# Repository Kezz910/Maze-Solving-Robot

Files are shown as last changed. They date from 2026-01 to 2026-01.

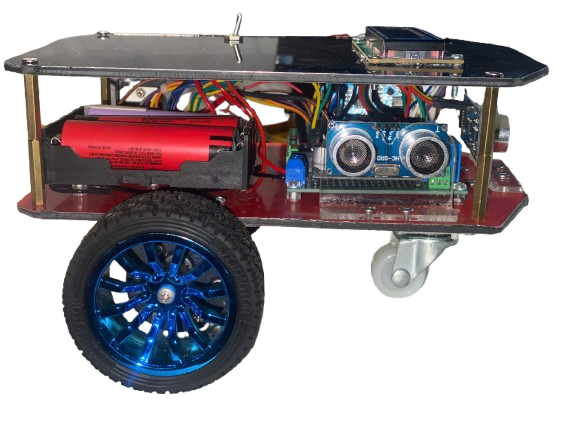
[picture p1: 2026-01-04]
hardware/ben_phai_robot.png

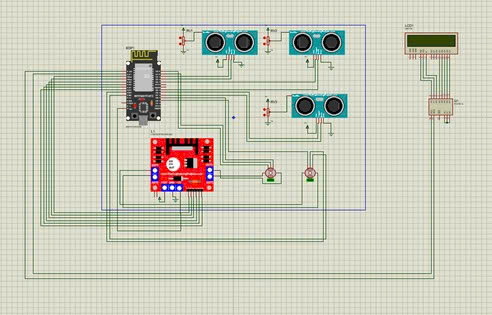
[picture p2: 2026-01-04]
hardware/sơ_đồ_nguyên_lý.jpg

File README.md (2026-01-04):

## Maze-Solving Robot (ESP32)

### 1. Tổng quan
Dự án xây dựng một robot tự hành có khả năng **tự di chuyển trong mê cung theo dạng lưới**, sử dụng cảm biến để nhận biết tường/vật cản và thuật toán để quyết định hướng đi.  
Hệ thống được thiết kế theo hướng **vừa vận hành thực tế vừa có khả năng giám sát dữ liệu**, nhằm phục vụ kiểm thử thuật toán và đánh giá chất lượng điều khiển trong môi trường mê cung.

Mục tiêu của đề tài là:
- Robot có thể **tự khám phá mê cung** và xử lý được các tình huống như ngã rẽ, vòng lặp, ngõ cụt.
- **Ghi nhận dữ liệu** (khoảng cách cảm biến, trạng thái di chuyển) để quan sát và phân tích trên dashboard.
- Ổn định chuyển động nhờ phản hồi encoder, giảm sai lệch do cơ khí và tải.

### 2. Kiến trúc hệ thống
Hệ thống gồm 3 lớp chính:

#### (1) Lớp cảm biến – nhận biết môi trường
Robot sử dụng **03 cảm biến siêu âm HC-SR04** bố trí theo 3 hướng **trước / trái / phải** để đo khoảng cách đến tường.  
Tại mỗi “bước” trong mê cung, robot cập nhật khoảng cách và phân loại đường đi: có thể đi thẳng, có thể rẽ, hoặc bị chặn.

#### (2) Lớp điều khiển chuyển động – chấp hành
Robot dùng **02 động cơ DC có encoder** điều khiển qua **L298N**. Encoder được dùng để:
- cân bằng tốc độ hai bánh khi đi thẳng,
- hỗ trợ điều khiển rẽ/quay ổn định hơn,
- hạn chế sai số tích lũy do lệch cơ khí.

Robot có LCD 16x2 (I2C) hiển thị thông tin cơ bản trong quá trình chạy.

#### (3) Lớp truyền thông – giám sát
Robot kết nối Wi-Fi và **truyền dữ liệu qua MQTT** (publish/subscribe). Dữ liệu được hiển thị bằng **Node-RED dashboard** để theo dõi realtime và hỗ trợ đánh giá quá trình chạy.

Nguồn cấp dùng pin 18650 cho phần công suất; khối điều khiển dùng hạ áp **LM2596** để ổn định cho ESP32 và ngoại vi.

### 3. Nguyên lý hoạt động (luồng thực thi)
Luồng chạy được tổ chức theo vòng lặp:
1. **Khởi tạo** ESP32, thiết lập GPIO/Timer, khởi tạo LCD và (tuỳ chọn) kết nối Wi-Fi + MQTT.
2. **Đọc cảm biến** (trước/trái/phải) để xác định các hướng có thể đi.
3. **Ra quyết định hướng đi** dựa trên luật ưu tiên và trạng thái đường đã đi (mục 4).
4. **Điều khiển động cơ**: phát PWM qua L298N; dùng encoder để cân bằng hai bánh và giảm lệch hướng.
5. **Cập nhật trạng thái**: lưu dấu đường đã đi trong ma trận biểu diễn mê cung, đồng thời gửi dữ liệu lên MQTT/Node-RED.
6. Lặp lại cho đến khi **tới đích** hoặc người dùng dừng.

Điểm quan trọng: robot di chuyển theo từng “ô” trong lưới mê cung; mỗi lần hoàn thành 1 ô thì mới cập nhật cảm biến và quyết định bước tiếp theo.

### 4. Thuật toán tìm đường và chiến lược tránh lặp
Robot áp dụng **thuật toán Trémaux** để xử lý mê cung có vòng lặp/ngõ cụt.  
Ý tưởng chính là **đánh dấu số lần đi qua mỗi ô/nhánh** (ví dụ: 0 – chưa đi, 1 – đã đi, 2 – hạn chế đi lại), từ đó:
- ưu tiên các hướng chưa đi qua,
- nếu gặp ngõ cụt thì quay lui,
- giảm khả năng chạy vòng lặp vô hạn.

Thuật toán được lưu bằng mảng/ma trận 2D đại diện lưới mê cung để robot có thể “nhớ” trạng thái đường đi.

### 5. Mô hình mê cung & thử nghiệm
Mê cung được thiết kế theo dạng lưới ô vuông để robot dễ quy ước di chuyển.  
Trong thử nghiệm:
- cảm biến siêu âm đáp ứng ổn định ở khoảng cách làm việc,
- động cơ hoạt động tốt với nguồn thực tế (có dòng khởi động lớn hơn dòng ổn định),
- việc dùng encoder giúp robot cân bằng tốt hơn, hạn chế lệch khi đi thẳng,
- Node-RED dashboard hiển thị dữ liệu theo thời gian thực, thuận tiện quan sát quá trình robot ra quyết định.

### 6. Cấu trúc thư mục repo
- `firmware/` : chương trình ESP32 (đọc cảm biến, điều khiển động cơ, encoder, MQTT)
- `hardware/` : sơ đồ đấu nối, mạch nguồn/driver, hình ảnh phần cứng
- `docs/` : mô tả hệ thống, lưu đồ, hình minh họa
- `results/` : hình ảnh, log, video minh họa kết quả chạy
- `algorithm` : Chi tiết thuật toán hoạt động thực tế

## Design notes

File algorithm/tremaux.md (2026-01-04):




# Mô tả chi tiết giải thuật lập trình (Maze Solving Robot)

## 1) Ý tưởng chung
Robot di chuyển theo các **cảm biến hợp lệ**:
- `cb0`: Thẳng
- `cb1`: Trái
- `cb2`: Phải

Quy tắc ưu tiên cơ bản: **Thẳng → Trái → Phải**, nhưng có xét thêm điều kiện **ô đã đi qua** (đánh dấu 0/1/2) để ưu tiên đi vào ô chưa đi lần nào.

Quy ước đánh dấu ô:
- `0`: chưa đi qua
- `1`: đã đi qua 1 lần
- `2`: đường cụt / đã quay đầu / đi lại

---

## 2) Bảng mô tả từng bước theo tọa độ

| Tọa độ | Hướng robot hiện tại | Cảm biến hợp lệ | Thực thi lệnh |
|---|---|---|---|
| (5,2) | BẮC | Trái (cb1) | Gọi hàm xoay trái 90° và đi thẳng. Đánh dấu ô (5,2) từ 0 → 1. |
| (5,1) | TÂY | Phải (cb2) | Xoay phải 90° và đi thẳng 1 ô. Đánh dấu ô = 1. |
| (4,1) | BẮC | Phải (cb2) | Xoay phải 90° và đi thẳng. Đánh dấu ô = 1. |
| (4,2) | ĐÔNG | Trái (cb1) | Xoay trái 90° và đi thẳng. Đánh dấu ô = 1. |
| (3,2) | BẮC | Trái (cb1) | Xoay trái 90° và đi thẳng. Đánh dấu ô = 1. |
| (3,1) | TÂY | Thẳng (cb0), Phải (cb2) | Ưu tiên **thẳng–trái–phải**. Thẳng→(3,0), phải→(2,1). Cả hai ô đều 0 nên ưu tiên **đi thẳng**. |
| (3,0) | TÂY | Trái (cb1) | Xoay trái 90° và đi thẳng. Đánh dấu ô = 1. |
| (5,0) | NAM | ĐƯỜNG CỤT | Xoay 180° và đi thẳng (quay đầu). Đánh dấu ô = 2. |
| (4,0) | BẮC | Thẳng (cb0) | Đi thẳng. Đánh dấu ô = 2. |
| (3,0) | BẮC | Phải (cb2) | Xoay phải và đi thẳng. Đánh dấu ô = 2. |
| (3,1) | ĐÔNG | Thẳng (cb0), Trái (cb1) | Thẳng và trái đều trống, nhưng thẳng→(3,2) đã = 1, còn trái→(2,1) chưa đi. ⇒ Xoay trái và đi thẳng. Đánh dấu (3,1) = 2. |
| (2,1) | BẮC | Phải (cb2) | Xoay phải và đi thẳng. Đánh dấu ô = 1. |
| (2,2) | ĐÔNG | Thẳng (cb0), Trái (cb1) | Ưu tiên đi thẳng vì 2 ô đều chưa đi qua lần nào. |
| (2,3) | ĐÔNG | Phải (cb2) | Xoay phải và đi thẳng. Đánh dấu ô = 1. |
| (3,3) | NAM | Thẳng (cb0), Trái (cb1) | Ưu tiên đi thẳng. Đánh dấu ô = 1. |
| (4,3) | NAM | Thẳng (cb0) | Chạy thẳng. Đánh dấu ô = 1. |
| (5,3) | NAM | ĐƯỜNG CỤT | Xoay 180° và đi thẳng. Đánh dấu ô = 2. |
| (4,3) | BẮC | Thẳng (cb0) | Đi thẳng. Đánh dấu ô = 2. |
| (3,3) | BẮC | Thẳng (cb0), Phải (cb2) | Thẳng không ưu tiên vì đã đi 1 lần, còn phải chưa đi ⇒ rẽ phải đi hướng mới. |
| (3,4) | ĐÔNG | Trái (cb1), Phải (cb2) | Hai ô đều 0 ⇒ ưu tiên rẽ trái. |
| (2,4) | BẮC | Thẳng (cb0) | Đi thẳng. Đánh dấu ô = 1. |
| (1,4) | BẮC | Thẳng (cb0), Trái (cb1) | Ưu tiên đi thẳng. Đánh dấu ô = 1. |
| (0,4) | BẮC | ĐƯỜNG CỤT | Xoay 180° và đánh dấu ô = 2. |
| (1,4) | NAM | Thẳng (cb0), Phải (cb2) | Thẳng→(2,4) đã đi 1 lần ⇒ loại. Xoay phải 90° và đi thẳng. Đánh dấu ô = 1. |
| (1,3) | TÂY | Thẳng (cb0) | Chạy thẳng. Đánh dấu ô = 1. |
| (1,2) | TÂY | Thẳng (cb0), Trái (cb1) | Thẳng→(1,1) chưa đi ⇒ chạy thẳng. |
| (1,1) | TÂY | Thẳng (cb0), Phải (cb2) | Ưu tiên chạy thẳng. Đánh dấu ô = 1. |
| (1,0) | TÂY | Trái (cb1) | Xoay trái 90° và đi thẳng. Đánh dấu ô = 1. |
| (2,0) | NAM | ĐƯỜNG CỤT | Xoay 180° và chạy thẳng. Đánh dấu ô = 2. |
| (1,0) | BẮC | Phải (cb2) | Xoay phải 90° và chạy thẳng. Đánh dấu ô = 2. |
| (1,1) | ĐÔNG | Thẳng (cb0), Trái (cb1) | Thẳng là ô đã đi 1 lần ⇒ ưu tiên rẽ trái và đi thẳng. |
| (0,1) | BẮC | (Đến đích) | Xét điều kiện đã đến đích ⇒ xe dừng chạy. |

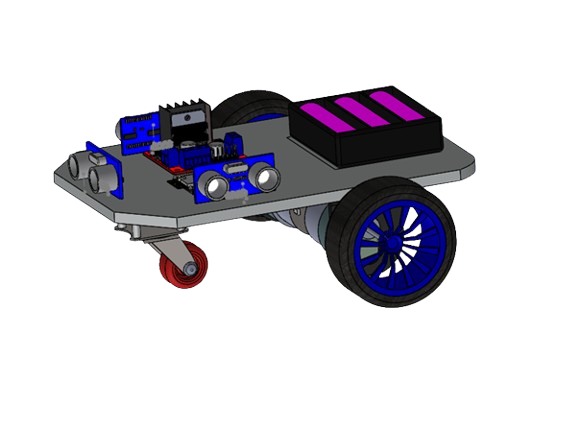
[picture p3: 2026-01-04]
hardware/SolidWorks/robot_3d.png

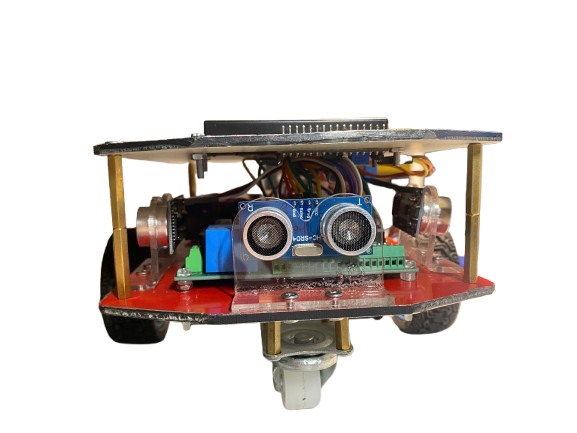
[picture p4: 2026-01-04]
hardware/phia_truoc_robot.png

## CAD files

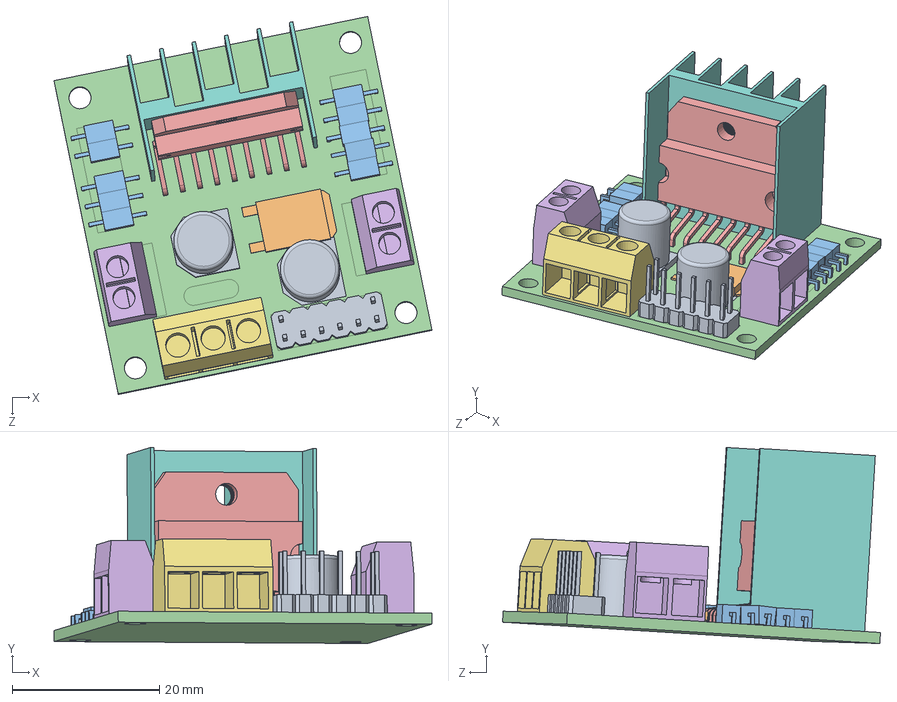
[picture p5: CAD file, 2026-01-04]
hardware/SolidWorks/ALL_L298N/L298N_LAPRAP.SLDASM
51.3 x 26.6 x 51.3 mm
Cam_chan_pin
chip_L298
DIODE x 10
L298N
L298N_to
Screw_terminal_2way x 2
screw_terminal_3way
Tan_nhiet
Tu_dien x 2

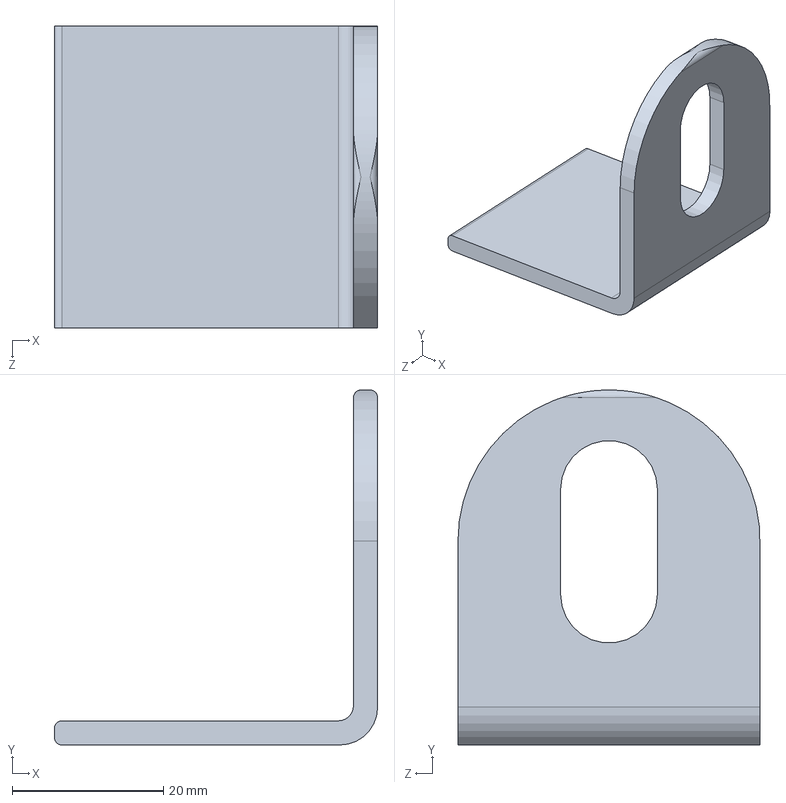
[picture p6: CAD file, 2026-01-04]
hardware/SolidWorks/ALL_Bxe_khung/Khung_motor.SLDPRT
42.8 x 47.0 x 40.0 mm

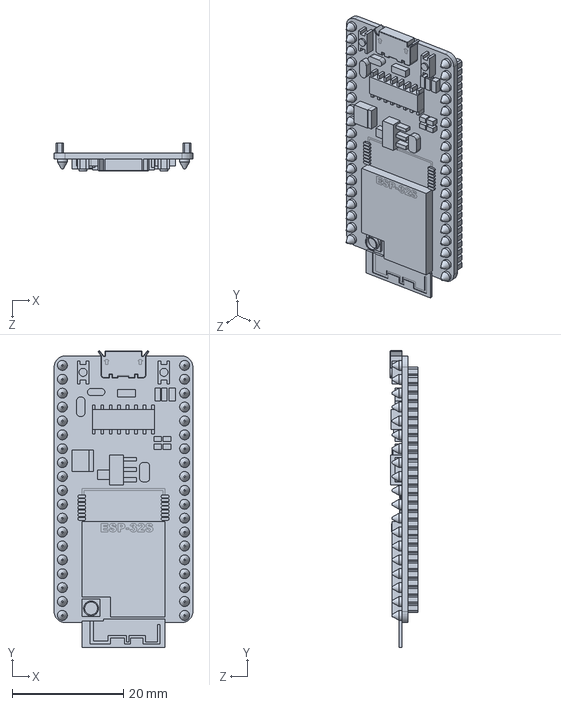
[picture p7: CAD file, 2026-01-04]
hardware/SolidWorks/esp32/esp32_wroom.SLDPRT
25.0 x 53.5 x 4.99 mm

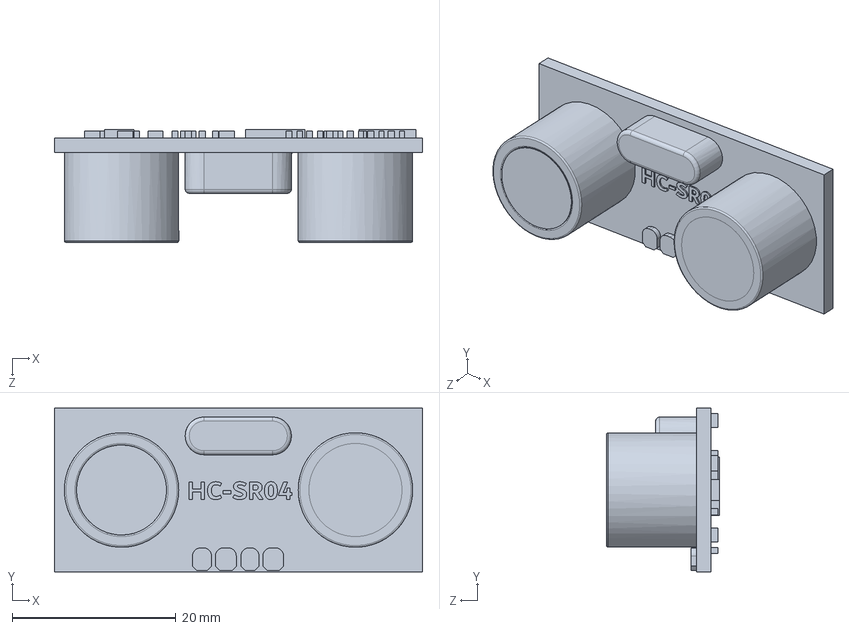
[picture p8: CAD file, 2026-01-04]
hardware/SolidWorks/HC_SR04/hc_rs04.SLDPRT
45.0 x 20.0 x 13.8 mm

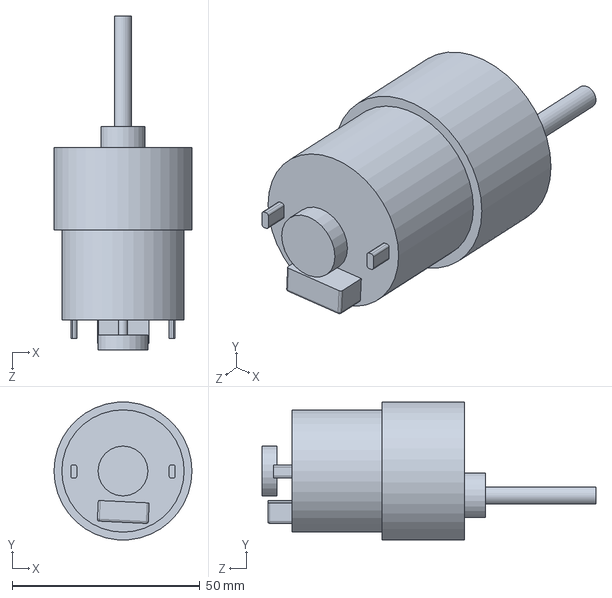
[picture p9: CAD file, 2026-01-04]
hardware/SolidWorks/ALL_Bxe_khung/motor_encoder.SLDPRT
36.8 x 36.7 x 89.0 mm

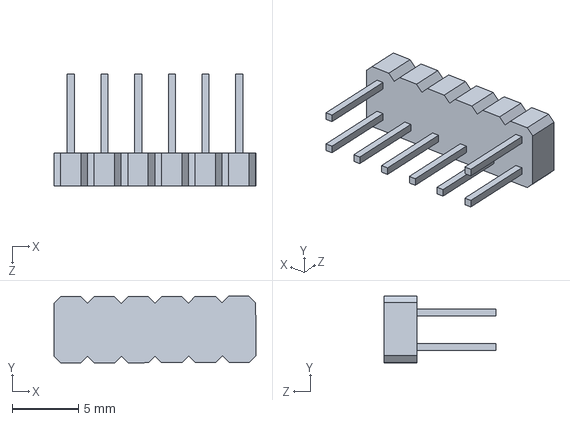
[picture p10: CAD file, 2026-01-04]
hardware/SolidWorks/ALL_L298N/Cam_chan_pin.SLDPRT
15.3 x 5.05 x 8.50 mm

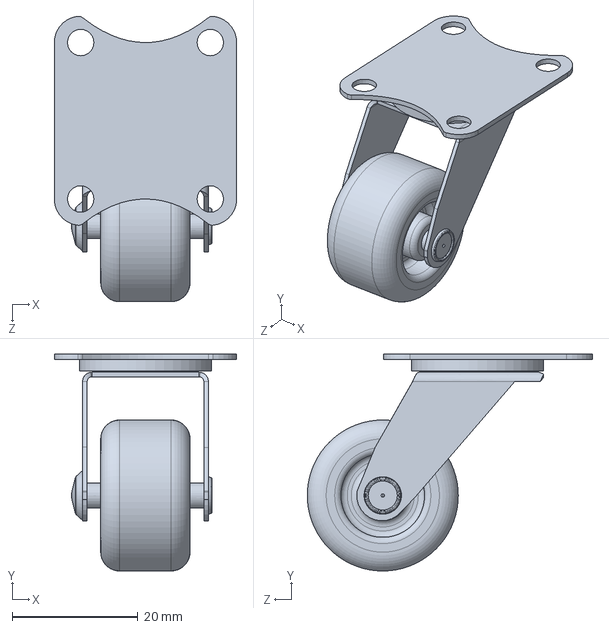
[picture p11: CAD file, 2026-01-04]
hardware/SolidWorks/ALL_Bxe_khung/caster_wheell.SLDPRT
29.0 x 34.5 x 45.4 mm

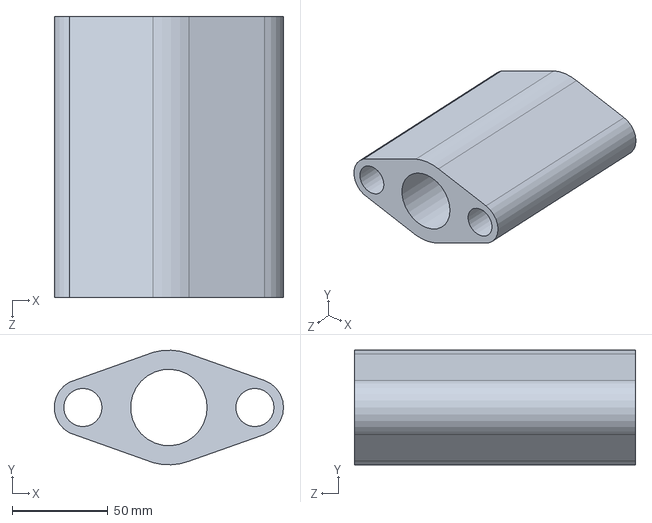
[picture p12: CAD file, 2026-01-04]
hardware/SolidWorks/ALL_L298N/Bai1_hoanthanh.SLDPRT
119.9 x 60.0 x 147.0 mm

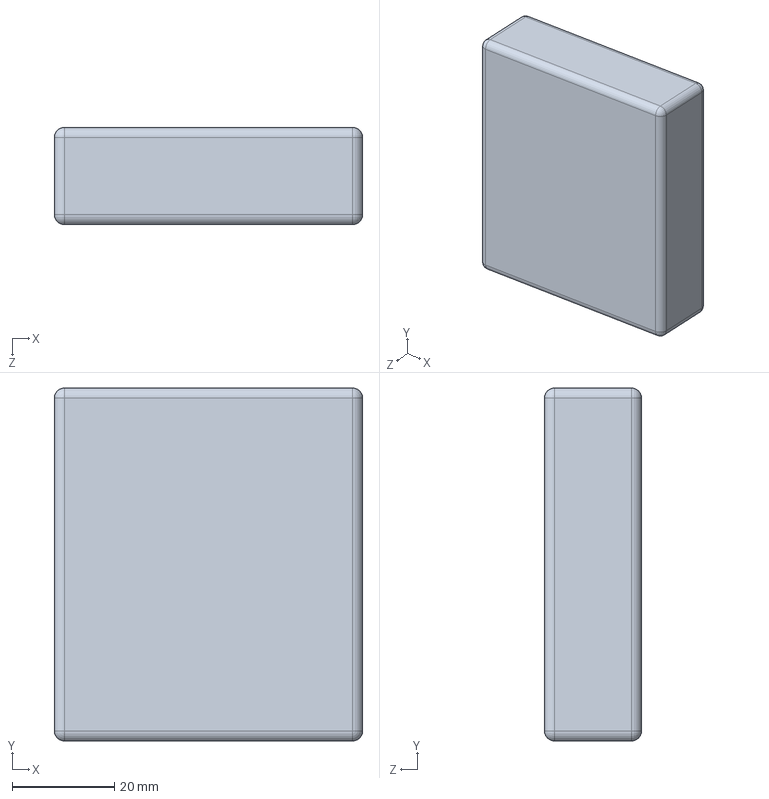
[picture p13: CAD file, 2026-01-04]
hardware/SolidWorks/ALL_Bxe_khung/case_18650.SLDPRT
60.3 x 69.0 x 19.0 mm

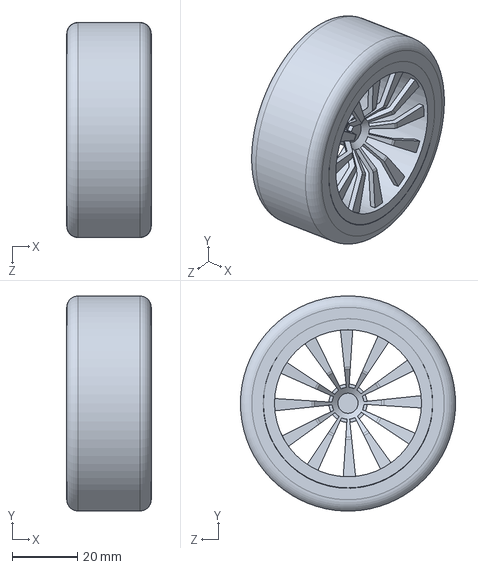
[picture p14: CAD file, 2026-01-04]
hardware/SolidWorks/ALL_Bxe_khung/banh_xe.SLDPRT
26.0 x 66.1 x 66.2 mm

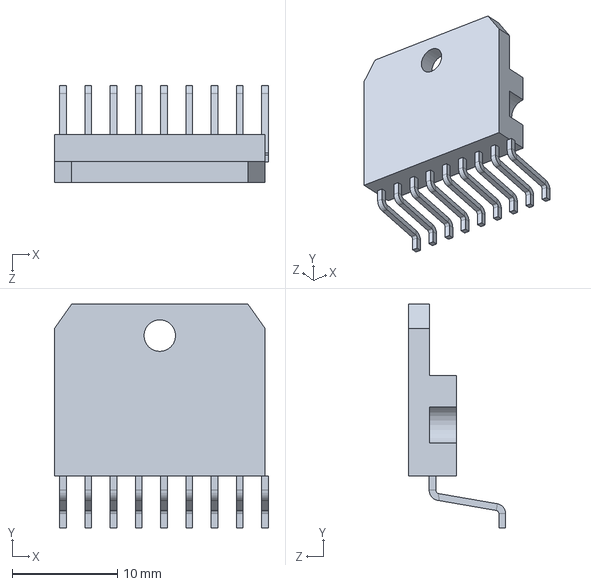
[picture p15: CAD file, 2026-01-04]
hardware/SolidWorks/ALL_L298N/L298N_to.SLDPRT
20.3 x 21.3 x 9.26 mm

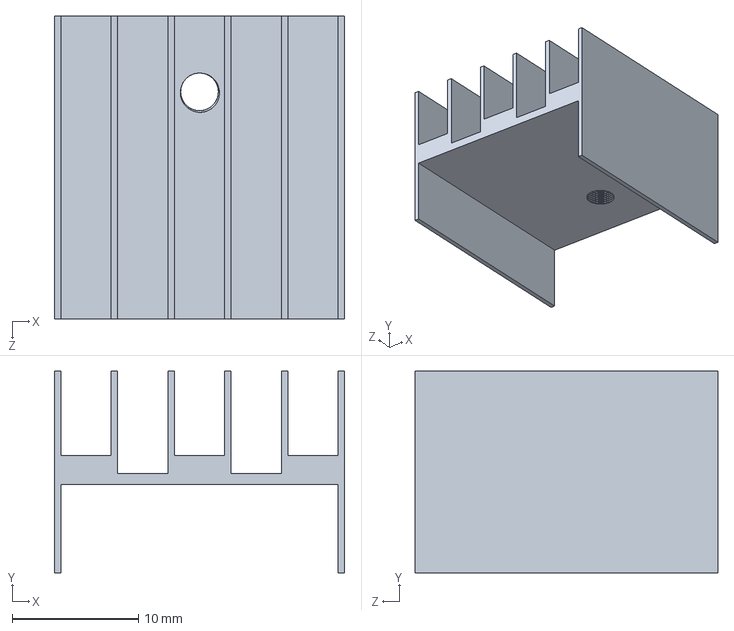
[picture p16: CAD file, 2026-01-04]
hardware/SolidWorks/ALL_L298N/Tan_nhiet.SLDPRT
23.0 x 16.0 x 24.0 mm

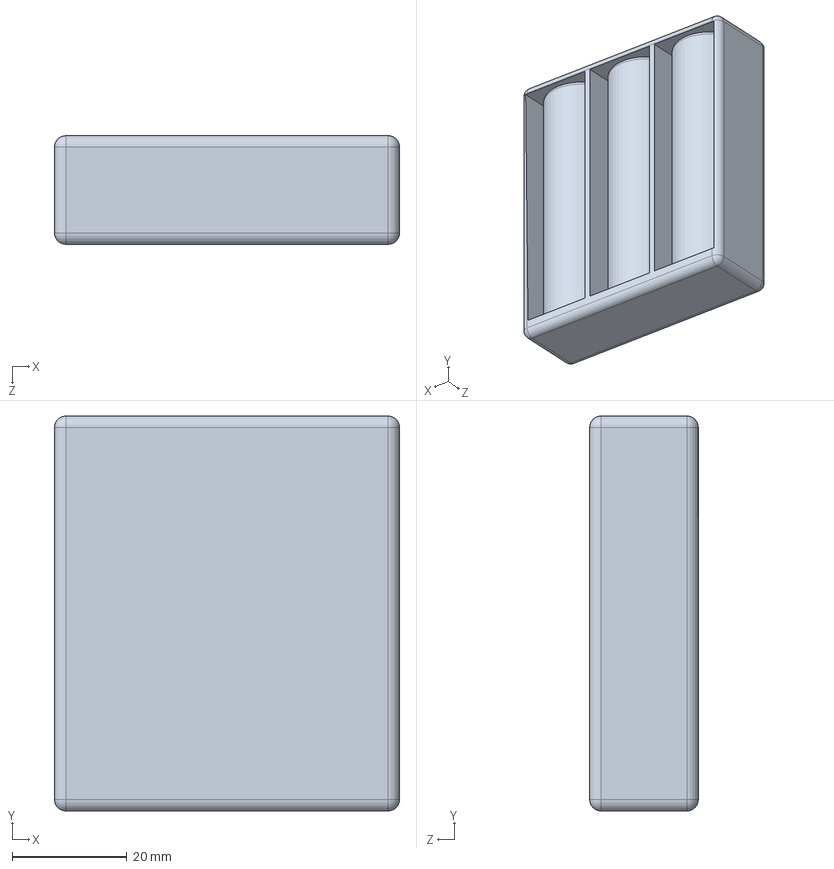
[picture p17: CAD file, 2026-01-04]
hardware/SolidWorks/ALL_Bxe_khung/pin_case.SLDPRT
60.3 x 69.0 x 19.0 mm

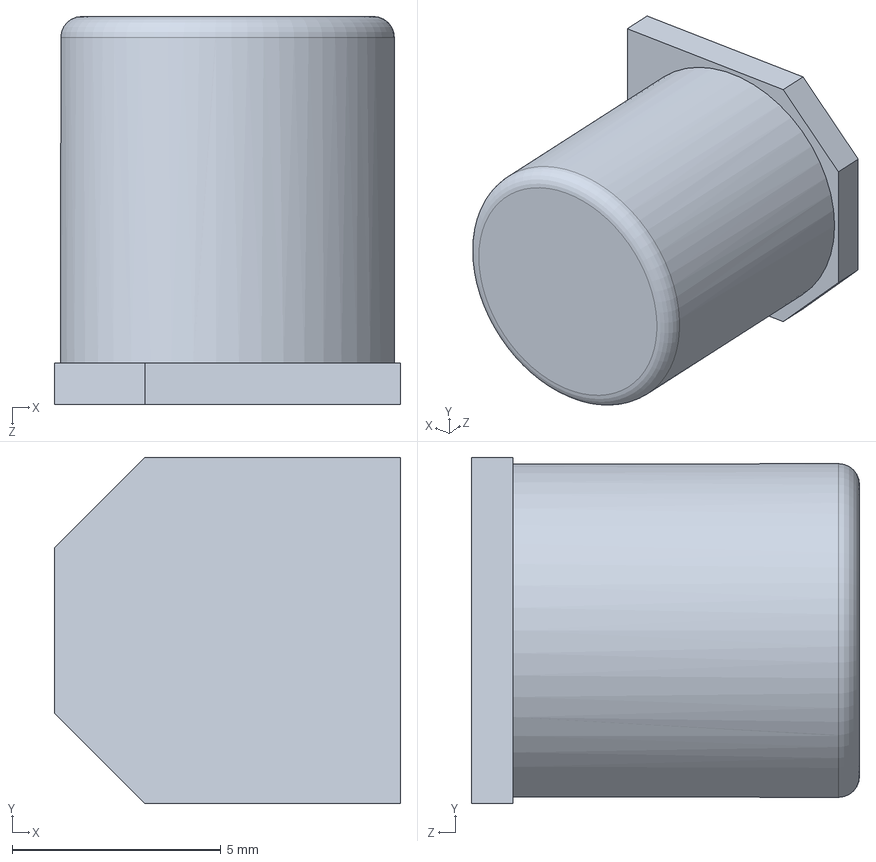
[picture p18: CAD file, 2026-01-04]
hardware/SolidWorks/ALL_L298N/Tu_dien.SLDPRT
8.30 x 8.30 x 9.30 mm

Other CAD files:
hardware/SolidWorks/ALL_L298N/Regulator_Capacitor.SLDPRT
hardware/SolidWorks/ALL_L298N/DIODE.SLDPRT
hardware/SolidWorks/ALL_L298N/chip_L298.SLDPRT
hardware/SolidWorks/ALL_L298N/Screw_terminal_2way.SLDPRT
hardware/SolidWorks/ALL_Bxe_khung/18650.SLDPRT
hardware/SolidWorks/ALL_L298N/screw_terminal_3way.SLDPRT

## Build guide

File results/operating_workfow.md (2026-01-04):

## Nguyên lý hoạt động 

### 1) Tổng quan phần cứng
Robot sử dụng:
- **03 cảm biến siêu âm HC-SR04** để đo khoảng cách trước / trái / phải (quy ước lần lượt: cb0 / cb1 / cb2).
- **02 động cơ DC có encoder (2 kênh)** để đo tốc độ/độ dịch chuyển, kết hợp bánh caster phía trước để hỗ trợ chuyển hướng.
- Nguồn cấp: **3 cell 18650 (3000 mAh/cell)** → qua mạch mở rộng, sử dụng LM2596 tạo nguồn ổn áp cấp cho ESP32.
- Mạch mở rộng dùng 74HC595N để mở rộng GPIO; đồng thời bổ sung phần cách ly/đệm tải (relay, transistor BC547, diode 1N4007, điện trở...) nhằm hạn chế xung đột và bảo vệ ESP32 khi điều khiển tải công suất.

---

### 2) Trình tự khởi động & truyền dữ liệu giám sát
Khi bật công tắc:
1. ESP32 khởi động và kết nối Wi-Fi.
2. Sau khi Wi-Fi OK, robot tiếp tục kết nối MQTT tới broker (server).
3. Khi MQTT kết nối thành công, hệ thống sẵn sàng và tự chạy sau ~5 giây.
4. Trong quá trình chạy, robot **đẩy dữ liệu khoảng cách (cb0/cb1/cb2)** lên hệ thống giám sát (Node-RED) theo từng “ô” trong mê cung.

---

### 3) Mô hình mê cung & quy ước tọa độ
- Mê cung có kích thước **6 × 5** (6 hàng, 5 cột).
- Mỗi ô được gán một tọa độ **(x, y)**.
- Tọa độ **xuất phát: (5, 2)** và tọa độ **đích: (0, 1)**.
- Robot di chuyển **theo từng ô** (đi hết 1 ô rồi mới cập nhật cảm biến và ra quyết định bước tiếp theo).

---

### 4) Điều khiển chuyển động: PID bám hướng / bám tường
Bộ điều khiển **PID** được dùng để ổn định chuyển động và giảm lệch hướng:
- Robot **bắt buộc đi thẳng hết 1 ô** trước khi đọc lại cảm biến và quyết định rẽ/đi thẳng/xoay.
- Khi **hai bên đều có tường**, PID giữ robot chạy cân bằng giữa hành lang.
- Khi **một bên mất tường**, robot chuyển sang **bám tường** theo phía còn lại.
- Khi **không có tường**, robot điều khiển 2 động cơ chạy “đồng đều” để đi thẳng hết 1 ô.

---

### 5) Thuật toán tìm đường: Trémaux + ưu tiên hướng
Robot áp dụng **thuật toán Trémaux** với nguyên tắc:
- **Mỗi ô không đi quá 2 lần**.
- Mỗi ô có “giá trị đánh dấu”:
  - `0`: chưa đi qua
  - `1`: đã đi qua 1 lần
  - `2`: đã đi qua 2 lần

**Luật ra quyết định tại ngã rẽ**
1. Robot quét trạng thái đường đi theo thứ tự ưu tiên hình học: **THẲNG → TRÁI → PHẢI** (ưu tiên hướng nào thông trước).
2. Ở tầng kiểm định Trémaux, robot sẽ ưu tiên:
   - Chọn ô có giá trị **0** (chưa đi qua) trước.
   - Nếu không còn ô giá trị 0 xung quanh, mới xét ô giá trị **1**.
3. Nếu gặp **đường cụt / bị chặn**, robot quay lại ngã rẽ gần nhất và tiếp tục xét các hướng còn khả dụng theo nguyên tắc trên.

> Tóm lại: robot kết hợp **ổn định chuyển động bằng PID** (đi theo từng ô) và **quy tắc Trémaux** (đánh dấu 0/1/2) để tìm đường trong mê cung theo chiến lược ưu tiên nhưng vẫn tránh lặp vô hạn.

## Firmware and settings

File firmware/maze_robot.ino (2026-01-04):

#include <WiFi.h>
#include <PubSubClient.h>
#include <ArduinoJson.h>
#include <Wire.h>
#include <LiquidCrystal_I2C.h>

// địa chỉ I2C LCD thường là 0x27 || 0x3F
LiquidCrystal_I2C lcd(0x27, 16, 2);

// ======= Cấu hình Wi-Fi & MQTT =======
const char* ssid     = "Minh Tuấn";
const char* password = "11111112";
const char* broker   = "test.mosquitto.org";
const int   mqttPort = 1883;
const char* clientID = "esp32_robot";

WiFiClient     espClient;
PubSubClient   mqtt(espClient);

// gọi trong bất cứ đâu nếu mất Wi-Fi
void wifiReconnect() {
  if (WiFi.status() == WL_CONNECTED) return;
  WiFi.disconnect();
  WiFi.begin(ssid, password);
  while (WiFi.status() != WL_CONNECTED) {
    delay(500);
  }
}

// gọi trong loop nếu mất MQTT
void mqttReconnect() {
  while (!mqtt.connected()) {
    mqtt.connect(clientID);
    delay(500);
  }
}
// khai báo chân I2C 
#define SDA_PIN 4
#define SCL_PIN 5

// --- Định nghĩa chân HC-SR04 -
// Cảm biến 0 (phía trước)
#define TRIG0 12
#define ECHO0 13

// Cảm biến 1 (bên trái)
#define TRIG1 14
#define ECHO1 27

// Cảm biến 2 (bên phải)
#define TRIG2 25
#define ECHO2 26

// Định nghĩa chân động cơ và chân encoder cho động cơ 1
#define IN1 16  // Chân điều khiển chiều dương động cơ 1
#define IN2 17  // Chân điều khiển chiều âm động cơ 1
#define A1 22   // Chân tín hiệu kênh A encoder của động cơ 1
#define B1 23   // Chân tín hiệu kênh B encoder của động cơ 1

// Định nghĩa chân động cơ và chân encoder cho động cơ 2
#define IN3 18  // Chân điều khiển chiều dương động cơ 2
#define IN4 19  // Chân điều khiển chiều âm động cơ 2
#define A2 32   // Chân tín hiệu kênh A encoder của động cơ 2
#define B2 33   // Chân tín hiệu kênh B encoder của động cơ 2

// Gia trị encoder ban đầu là 0 cho 2 động cơ 
volatile int vitri1 = 0;   // Vị trí động cơ 1
volatile int vitri2 = 0;   // Vị trí động cơ 2

// --- Các hằng số điều khiển ---
#define NGUONG 22  // Ngưỡng khoảng cách an toàn (cm) của cảm biến phía trước
#define NGUONG_MEM 18 


//Các biến cho hàm PID
double lastErr;
double lastTime;
double errSum;


// --- Hàm đo khoảng cách từ cảm biến ---
float doKhoangCach(int trig, int echo) {
  digitalWrite(trig, LOW);
  delayMicroseconds(2);
  digitalWrite(trig, HIGH);
  delayMicroseconds(10);
  digitalWrite(trig, LOW);
  
  long doDaiXung = pulseIn(echo, HIGH);
  float khoangCach = doDaiXung * 0.034 / 2;  // Tính khoảng cách (cm)
  return khoangCach;
}


// --- Hàm cập nhật vị trí encoder ---
void updateVitri1() {
  if (digitalRead(B1) == HIGH)
    vitri1--;
  else
    vitri1++;
}

void updateVitri2() {
  if (digitalRead(B2) == HIGH)
    vitri2++;
  else
    vitri2--;
}



// --- Hàm quay động cơ theo chiều dương/âm ---
void quay(int speedL, int speedR) {
  if(speedL > 0) {
    analogWrite(IN2, speedL);
    analogWrite(IN1, 0);
  }else if(speedL < 0) {
    analogWrite(IN1, abs(speedL));
    analogWrite(IN2, 0);
  }else{ //Trường hợp còn lại là speedL = 0 đẩy lên cao để phanh bằng motor, hạn chế trôi
    analogWrite(IN2, 255);
    analogWrite(IN1, 255);
  }

  if(speedR > 0) {
    analogWrite(IN3, speedR);
    analogWrite(IN4, 0);
  }else if(speedR < 0) {
    analogWrite(IN4, abs(speedR));
    analogWrite(IN3, 0);
  }else{ //Trường hợp còn lại là speedR = 0 đẩy lên cao để phanh bằng motor, hạn chế trôi
    analogWrite(IN3, 255);
    analogWrite(IN4, 255);
  }
}





//Hàm PID đơn giản để điều khiển motor
int simplePID(float Setpoint, float Input, float kp, float ki, float kd) {
  /*How long since we last calculated*/
  unsigned long now = micros();
  double timeChange = (double)(now - lastTime) * 0.000001;

  /*Compute all the working error variables*/
  double error = Setpoint - Input;
  errSum += (error * timeChange);
  double dErr = (error - lastErr) / timeChange;

  /*Compute PID Output*/
  float Output = kp * error + ki * errSum + kd * dErr;

  lastErr = error;
  lastTime = now;
  return (int)Output;
}

///////////////////////////////////////////
enum huong{ BAC = 0,DONG = 1, NAM = 2, TAY = 3};
huong huonght = BAC; 

const int dr[4] = {-1, 0, 1, 0};
const int dc[4] = { 0, 1, 0, -1};

///////////////////////////////////////////////
#define ROWS 6
#define COLS 5 

int row =3;
int col =2;
const int goalR = 1;
const int goalC = 3;
bool reached = false; 

// taọ mảng 2D đầu tiên để lưu giá trị mỗi lần đi qua của map 
uint8_t maze[ROWS][COLS] = {
  {0 , 0 , 0 , 0 , 0},
  {0 , 0 , 0 , 0 , 0},
  {0 , 0 , 0 , 0 , 0},
  {0 , 0 , 0 , 0 , 0},
  {0 , 0 , 0 , 0 , 0},
  {0 , 0 , 0 , 0 , 0}
};
//Hàm đi thẳng
void dithang()
{

  const float Kp = 1.0;
  const float Ki = 0;
  const float Kd = 0.8;
  const int baseSpeed = 90;
  const int motO = 560;  // so cu là 538 xung
  const int SETPOINT = 12;  // giá trị bám 1 bên tường
  const int NGUONG_DT = 18; // vì khi robot bám 1 bên tường thì có lúc sẽ vượt ra khỏi ngưỡng , do đó nó lọt vào trường hợp cuối nên chạy đều , xử lý vấn đề này tạo thêm cho nó một giới hạn
  const int NGUONG_1 = 16;

  int vitri1_bandau = vitri1;
  int vitri2_bandau = vitri2;

  while (abs(vitri1 - vitri1_bandau) < motO && abs(vitri2 - vitri2_bandau) < motO)
  {
    wifiReconnect();
    if (!mqtt.connected()) mqttReconnect();
    mqtt.loop();
    float kctruoc = doKhoangCach(TRIG0, ECHO0);
    float kctrai = doKhoangCach(TRIG1, ECHO1);
    float kcphai = doKhoangCach(TRIG2, ECHO2);

    bool Trai = kctrai < NGUONG_DT;
    bool Phai = kcphai < NGUONG_DT;
    bool Truoc = kctruoc < NGUONG_1;
    int adjustment = 0;

    if (!Truoc && Trai && Phai)
    {
      adjustment = simplePID(0, kctrai - kcphai, Kp, Ki, Kd);
      quay(baseSpeed + adjustment, baseSpeed - adjustment);
    }
    else if (!Truoc && !Trai && Phai)
    {
      adjustment = simplePID(SETPOINT, kcphai, 4, 0 , 1.3);
      quay(90 - adjustment, 90  + adjustment);
    }
    else if (!Truoc && Trai && !Phai)
    {
      adjustment = simplePID(SETPOINT, kctrai, 4, 0 , 1.3);  // bam traiiiiiiiiiiiiiiii
      quay(90 + adjustment, 90 - adjustment);
    }
    else if (!Truoc && !Trai && !Phai)
    {
      quay(78,78);
    }
    delay(10);
  }

 quay(0, 0);
}

// --- Hàm quay 90 độ ---
void quayphai90() {
  int target = 190;  // 90 độ là 182 xung 
  int start1 = vitri1;
  int start2 = vitri2;

  quay(110, -110);

  while ( abs(vitri1 - start1) < target && abs(vitri2 - start2) < target ) {
    wifiReconnect();
    if (!mqtt.connected()) mqttReconnect();
    mqtt.loop();
    delay(10); // Chờ cho đến khi quay đủ 90°
  }
  huonght = (huong)((huonght + 1)%4); // cập nhật hướng sau khi quay phải 90 độ 
  quay(0,0);
}

void quaytrai90() {
  int target = 189;  // 90 độ là 182 xung 
  int start1 = vitri1;
  int start2 = vitri2;

  quay(-110, 110);

  while ( abs(vitri1 - start1) < target && abs(vitri2 - start2) < target ) {
    wifiReconnect();
    if (!mqtt.connected()) mqttReconnect();
    mqtt.loop();
    delay(10); // Chờ cho đến khi quay đủ 90°
  }
  huonght = (huong)((huonght + 3)%4); // cập nhật hướng sau khi quay trái 90 độ 
  quay(0,0);
}

void quay180(){
  int target = 470;  // 180 độ là 412 xung (theo tính toán)

  int start1 = vitri1;
  int start2 = vitri2;

  quay(78, -80);

  while ( abs(vitri1 - start1) < target && abs(vitri2 - start2) < target ) {
    wifiReconnect();
    if (!mqtt.connected()) mqttReconnect();
    mqtt.loop();
    delay(10); // Chờ cho đến khi quay đủ 180
  }
  huonght = (huong)((huonght + 2)%4); // cập nhật hướng sau khi quay 180 độ 
  quay(0,0);
}

void inmap() {
  // 1) Tiêu đề hàng đầu, có xuống dòng
  Serial.println(F("------ MAZE MAP ------"));
  
  // 2) In từng hàng, mỗi ô cách nhau 1 dấu cách
  for (int i = 0; i < ROWS; i++) {
    for (int j = 0; j < COLS; j++) {
      Serial.print(maze[i][j]);
      Serial.print(F(" "));
    }
    Serial.println();       // xuống dòng sau khi in hết 1 hàng
  }

  // 3) In thêm 1 dòng trống để tách biệt với lần in kế tiếp
  Serial.println();
}
void capNhatToaDo() {
  // lưu lại ô cũ trước khi di chuyển 
  int oldRow = row;
  int oldCol = col;
  
  switch (huonght) {
    case BAC:  row--; break;  // Di chuyển lên, giảm hàng
    case DONG: col++; break;  // Di chuyển phải, tăng cột
    case NAM:  row++; break;  // Di chuyển xuống, tăng hàng
    case TAY:  col--; break;  // Di chuyển trái, giảm cột
  }

  row = constrain(row, 0, ROWS-1);
  col = constrain(col, 0, COLS-1);
  
  maze[oldRow][oldCol]++;

  inmap();

}



// --- Hàm setup ---
void setup() {
  Serial.begin(115200);

  // 1) Khởi I2C & LCD
  Wire.begin(SDA_PIN, SCL_PIN);      // SDA=4, SCL=5
  lcd.init();
  lcd.backlight();

  // 2) Hiện “Connecting WiFi…”
  lcd.clear();
  lcd.print("Connecting WiFi");
  lcd.setCursor(0,1);
  // 3) Kết nối WiFi
  wifiReconnect();
  // Wi-Fi OK
  lcd.clear();
  lcd.print("WiFi connected");
  delay(1000);

  // 4) Cấu hình broker + kết nối MQTT
  mqtt.setServer(broker, mqttPort);
  lcd.clear();
  lcd.print("Connecting MQTT");
  lcd.setCursor(0,1);
  if (mqtt.connect(clientID)) {
    lcd.print(" OK");
  } else {
    lcd.print(" FAIL");
  }
  delay(1000);

  // 5) Khởi HC-SR04 / encoder / motor
  pinMode(TRIG0, OUTPUT);
  pinMode(ECHO0,  INPUT);
  pinMode(TRIG1, OUTPUT);
  pinMode(ECHO1,  INPUT);
  pinMode(TRIG2, OUTPUT);
  pinMode(ECHO2,  INPUT);

  pinMode(A1, INPUT);  pinMode(B1, INPUT);
  pinMode(A2, INPUT);  pinMode(B2, INPUT);
  pinMode(IN1, OUTPUT); pinMode(IN2, OUTPUT);
  pinMode(IN3, OUTPUT); pinMode(IN4, OUTPUT);

  attachInterrupt(digitalPinToInterrupt(A1), updateVitri1, RISING);
  attachInterrupt(digitalPinToInterrupt(A2), updateVitri2, RISING);

  lastTime = micros();
  lastErr  = 0;
  errSum   = 0;

  delay(5000);
}



// --- Hàm loop ---
void loop() {

  wifiReconnect();
  // 2) Giữ MQTT
  if (!mqtt.connected()) mqttReconnect();
  mqtt.loop();
  // đọc cảm biến trước, trái, phải 
  float kctruoc = doKhoangCach(TRIG0, ECHO0);  // Cảm biến phía trước
  float kctrai = doKhoangCach(TRIG1, ECHO1);   // Cảm biến bên trái
  float kcphai = doKhoangCach(TRIG2, ECHO2);   // Cảm biến bên phải

  // 3) Gói JSON và publish lên Node-RED
  StaticJsonDocument<128> doc;
  doc["front"] = kctruoc;
  doc["left"]  = kctrai;
  doc["right"] = kcphai;
  char buf[128];
  size_t len = serializeJson(doc, buf);
  mqtt.publish("esp32_robot/sensors", buf, len);

    // … sau khi publish MQTT xong …

  // Làm tròn về int
  int d0 = int(kctruoc);
  int d1 = int(kctrai);
  int d2 = int(kcphai);

  char buff[17];

  // Hàng 1: CB0 ở giữa
  lcd.clear();
  // "CB0:xxcm" dài 8 ký tự, đặt ở cột (16–8)/2 = 4
  lcd.setCursor(4, 0);
  sprintf(buff, "cb0:%2dcm", d0);
  lcd.print(buff);

  // Hàng 2: CB1 bên trái, CB2 bên phải
  lcd.setCursor(0, 1);
  sprintf(buff, "cb1:%2dcm ", d1);
  lcd.print(buff);
  // "CB2:xxcm" cũng dài 8, đặt ở cột 16−8=8
  lcd.setCursor(8, 1);
  sprintf(buff, " cb2:%2dcm", d2);
  lcd.print(buff);


  

  int hople = 0;
  int nr[4], nc[4], nd[4], rels[4]; // lưu hàng , cột và hướng của ô mà có thể đi được trong 4 hướng 
  for(int d=0; d<4 ; d++)
  {
     int r2 = row + dr[d];
     int c2 = col + dc[d];
     if(r2 < 0 || r2 >= ROWS || c2 <0 || c2 >= COLS) continue; 

     // xác định hướng cần đi so với hướng hiện tại theo ưu tiên trái - thẳng phải 
     int rel = (d - huonght +4)%4 ;

     // lấy hướng xong thì cần qua một ải kiểm tra nữa là xét nó với ngưỡng 
     bool wall = false ; 
     if (rel == 0 && kctruoc < NGUONG ) wall = true; 
     else if (rel == 3 && kctrai  < NGUONG_MEM ) wall = true; 
     else if (rel == 1 && kcphai  < NGUONG_MEM ) wall = true; 

     if (wall) continue; 

     // lưu ô nào thông để chạy 
     nr[hople] = r2; 
     nc[hople] = c2;
     nd[hople] = d;
     rels[hople] = rel;
     hople++;
  }
     // chọn hướng theo trémaux 
     const int PRI[4] = {0,3,1,2};
     int chosen = -1; 

     // pass 1: tìm ô chưa visit (maze==0)
  for (int p = 0; p < 4 && chosen < 0; p++) {
    for (int i = 0; i < hople; i++) {
      if (rels[i] == PRI[p] && maze[nr[i]][nc[i]] == 0) {
        chosen = i;
        break;
      }
    }
  }
  // pass 2: nếu không có, tìm ô đã visit đúng 1 lần
  if (chosen < 0) {
    for (int p = 0; p < 4 && chosen < 0; p++) {
      for (int i = 0; i < hople; i++) {
        if (rels[i] == PRI[p] && maze[nr[i]][nc[i]] == 1) {
          chosen = i;
          break;
        }
      }
    }
  }
  // dead-end: backtrack
  if (chosen < 0) {
    quay180();
    dithang();
    capNhatToaDo();
    return;
  }

  // 4. Thực thi quay → di chuyển → cập nhật
  huong nextDir = (huong) nd[chosen];
  if      (nextDir == huonght) {
    // thẳng
  }
  else if (nextDir == huong((huonght + 1) % 4)) {
    quayphai90();
  }
  else if (nextDir == huong((huonght + 3) % 4)) {
    quaytrai90();
  }
  else {
    quay180();
  }

  dithang();
  capNhatToaDo();

  
   if (!reached && row == goalR && col == goalC) {
    reached = true;
    quay(0, 0);
    Serial.println(F(">>> Reached goal at (0,3)!"));
    while (true) delay(100);
  }
 delay(60);
}
